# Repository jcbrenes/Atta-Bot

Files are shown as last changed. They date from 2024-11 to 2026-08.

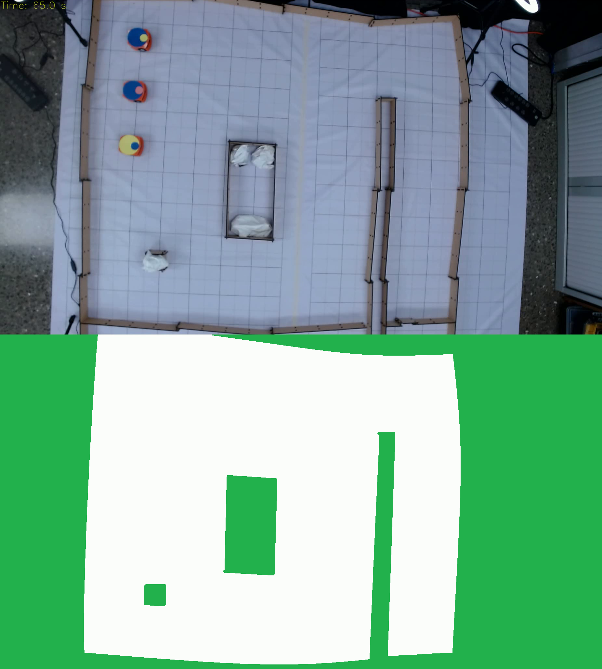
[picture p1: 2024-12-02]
Base/mask.png

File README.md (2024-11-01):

# Atta-Bot

Atta-Bot is a robotics system for swarm robotics research. Each Atta-Bot is a small, afordable and DIY mobile robot, but it also includes a base and camera system for robot tracking and position estimation.

Developed by the Multiple Robotics Research Group (GIRoM) at the Costa Rica Institute of Technology.

## Current Research Team
- Cindy Calderón Arce. ORCID: https://orcid.org/0000-0002-0077-225X  
- Rebeca Solís Ortega. ORCID: https://orcid.org/0000-0002-3065-8386  
- Juan Carlos Brenes Torres. ORCID: https://orcid.org/0000-0001-6323-2173  

## Folder directory
- Base -> Code for the computer running as the base with camera
- Docs -> Documentation on materials, construction, system architecture 
- Chassis -> Construction files and 3D models for the robot chassis
- Controller -> Code for the robot's microcontroller
- Scenario -> Construction files and 3D models for the swarm scenario 

## Coding standard
Please follow the coding or programming standard for any contribution to the project [Contributing.md]

[Contributing.md]: <https://github.com/jcbrenes/Atta-Bot/blob/main/Contributing.MD>

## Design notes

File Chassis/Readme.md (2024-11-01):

# Robot chassis 

Solid Works 3D files of robot chassis and 2D files for laser cutting.

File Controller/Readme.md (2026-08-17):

# Firmware del robot

Código C++ del microcontrolador de cada AttaBot. Un robot con este firmware
levanta WiFi, se anuncia a la estación base, obedece los comandos que le llegan
por UDP y ejecuta por su cuenta la navegación, la evasión de obstáculos y las
conductas de enjambre.

| carpeta | qué es |
|---|---|
| `AttaBot/` | el firmware normal, el que va en todos los robots |
| `HW_Test/` | diagnóstico de hardware sin WiFi — ver `Docs/HW_Test.md` |
| `IR_Calibration/` | calibración de los sensores infrarrojos |

---

## Qué hace falta

**Hardware:** ESP32 (módulo clásico, no S2/S3), dos motores DC con encoder y
puente H, dos sensores infrarrojos laterales, un APDS9960 al frente (proximidad y
color), una IMU ICM-20948, un anillo de LEDs y un marcador ArUco en la tapa.
El diagrama electrónico y la lista de materiales están en `Docs/`.

**Software:** el Arduino IDE (por su `arduino-cli` incorporado y su gestor de
librerías) o el `arduino-cli` suelto. Python 3 para `OTA.py`.

**Librerías**, con las versiones contra las que compila hoy:

| componente | versión |
|---|---|
| ESP32 Arduino core | 3.3.11 |
| FastLED | 3.10.5 |
| Adafruit APDS9960 | 1.3.1 |
| SparkFun ICM-20948 | 1.3.2 |

Estas versiones importan más de lo habitual: varias de estas librerías tienen
requisitos que **no se ven al compilar**. El sketch construye igual y el robot
arranca igual, y la falla aparece recién al moverlo. Las tres trampas conocidas
están en [Restricciones](#restricciones-que-hay-que-respetar), al final.

**Red:** los robots se conectan a un AP con el SSID y la contraseña que declara
`AttaBot/AttaBot.ino` (constantes `ssid` y `password`), y escuchan UDP en el
puerto 6060. Cada robot necesita IP fija en el router, y esa IP se anota en
`Base/configSystem.json` para que la base sepa a quién le habla.

---

## Compilar y subir

### La primera vez en cada robot: por USB

Obligatorio, porque `partitions.csv` cambia la tabla de particiones y eso no se
puede hacer por OTA — el OTA escribe en el slot de aplicación, nunca en la tabla.

```sh
cd Controller/AttaBot
arduino-cli compile --fqbn esp32:esp32:esp32:PartitionScheme=min_spiffs \
    --build-path build --upload --port /dev/ttyUSB0 .
arduino-cli monitor --port /dev/ttyUSB0 --config baudrate=115200
```

`arduino-cli board list` dice en qué puerto quedó el robot. Si se usa el que
viene dentro del Arduino IDE, el binario está en
`<instalación del IDE>/resources/app/lib/backend/resources/arduino-cli`.

> **`PartitionScheme=min_spiffs` no es decorativo.** `partitions.csv` le da al
> sketch un slot de 1.97 MB en vez de los 1.31 MB del layout por defecto. Sin
> declararlo, `arduino-cli` compila igual pero mide contra el slot equivocado y
> reporta 93 % de uso cuando el real es 62 %.

### Después: por aire

`OTA.py` compila y sube por WiFi en un solo paso, usando el `arduino-cli` del
IDE:

```sh
cd Controller/AttaBot
python3 OTA.py --build          # compila y sube a todos los robots
python3 OTA.py --build 101 104  # solo a .101 y .104
python3 OTA.py 101              # sube lo ya compilado
```

Antes de subir verifica que el `.bin` sea más nuevo que **todos** los `.ino` y
`.h` del sketch. Un OTA que sube un binario viejo es indistinguible de uno que
funciona, hasta que se prueba el robot.

### Desde VS Code

Las mismas operaciones están como tareas: `firmware: compilar y subir por USB`,
`ver puertos USB` y `monitor serie`. `vscode_setup.py` genera el
`c_cpp_properties.json` con las rutas del core de esta máquina (no se versiona,
porque son rutas absolutas).

---

## Estructura del sketch

Arduino concatena todos los `.ino` de la carpeta en una sola unidad de
traducción — primero el que se llama como la carpeta, después el resto en orden
alfabético. Por eso las constantes, las variables globales y las declaraciones
forward viven en `AttaBot.ino` y los demás archivos las ven directo, sin `extern`
ni cabeceras. La contra es que no hay encapsulación real: cualquier archivo puede
tocar cualquier global.

| archivo | qué lleva |
|---|---|
| `AttaBot.ino` | debug, pines, constantes, globales, declaraciones, ISR, `setup()` |
| `comandos.ino` | protocolo con la base y un handler por comando UDP |
| `estados.ino` | `loop()` y una función por estado de la FSM |
| `navegacion.ino` | navegación reactiva, congregación, MEET, dispersión, formaciones |
| `sensores.ino` | IR laterales, APDS9960 central, WiFi |
| `motores.ino` | PID por rueda, puente H, movimiento por distancia |
| `perifericos.ino` | LED, IMU y el EKF |
| `utils.h` | estructuras de estado y helpers inline |

El robot es una máquina de estados que consume una lista de instrucciones: los
comandos que llegan por UDP encolan instrucciones, y `loop()` ejecuta la que
toca. La lista de comandos y su sintaxis están en `Docs/comandos.md`; la
geometría de las formaciones, en `Docs/formaciones.md`.

Cada robot guarda en NVS su calibración propia (escala del giróscopo, pulsos por
revolución de los encoders, balance de blancos del sensor de color), así que dos
robots con el mismo binario no se comportan igual hasta calibrarlos. La rutina
guiada es `BASE.CALIBRATE|<id>` desde la consola de la base.

---

## Restricciones que hay que respetar

Tres detalles de las librerías rompen el robot **en silencio**: compilan bien y
la falla aparece recién al moverlo. Si algo de esto se toca, hay que verificarlo
en el arranque por serie.

### El PWM de los motores necesita el reloj APB

Los cuatro timers low-speed del LEDC **comparten un solo mux de reloj**. Los
motores van a 1 kHz / 14 bit, o sea 16.384 MHz de fuente, y eso sólo sale de APB
(80 MHz). Si otro periférico se queda con un reloj lento, los `ledcAttach()` de
los motores fallan y **las ruedas no reciben PWM: el robot no gira ni avanza**.

`setup()` deja el reloj explícito con `ledcSetClockSource(LEDC_USE_APB_CLK)`
antes de crear cualquier canal, así el reparto no se hereda de quien se attachee
primero. Si se monta un servo u otro periférico PWM:

- Dale **16 bits** de ancho de timer (pide 3.28 MHz → divisor 24 sobre APB), no
  los 10 por defecto. A 10 bits un servo pide 50 Hz × 2¹⁰ = 51.2 kHz, que desde
  APB daría divisor 1562 y no entra en el registro, así que el driver se va al
  reloj lento y arrastra a los motores.
- **No uses ESP32Servo 3.2.1**: su `attach()` pisa el ancho con el valor por
  defecto aunque la librería documente lo contrario. Sale más barato
  `ledcAttach(pin, 50, 16)` + `ledcWrite(pin, us << 16 / 20000)`.

Para verificarlo sin destapar nada, mirá el arranque por serie:

```
[3] Motores PWM: 1000Hz 14-bit (max=16383) OK — real=1000Hz
```

`FALLO`, o un `real=` distinto de 1000 Hz, es exactamente este problema.

### FastLED secuestra `radians()` — no la uses en este sketch

`FastLED.h` hace `#undef radians` y después `using fl::radians`. En el sketch
`radians()` **no es la macro de Arduino**, es esta plantilla:

```cpp
template<typename T>
constexpr inline T radians(T deg) { return deg * static_cast<T>(0.017453292519943295); }
```

La constante se castea al **tipo del argumento**. Con un ángulo entero,
`static_cast<int>(0.01745…)` es **0**, así que `radians(180)` devuelve **0** y
cualquier giro calculado desde un entero se vuelve un no-op silencioso. Con
`float` funciona bien.

El síntoma es característico porque separa los caminos por tipo: el robot
*navega* hacia el objetivo (la nav usa floats) pero *no esquiva* obstáculos
(ángulo de evasión entero), el random walk no gira y `TURN|grados` no hace nada
en ningún robot. Es fácil confundirlo con un problema de calibración por robot, y
no lo es.

Usá **`DegToRad()`** y **`DegToArc()`**, definidas al principio de `AttaBot.ino`:
toman `float` a propósito, para forzar la promoción en el call site, y usan la
constante literal sin depender de FastLED ni de `DEG_TO_RAD`.

La misma cabecera también reemplaza `abs`, `min`, `max`, `degrees` y `map`. Hoy
el firmware no usa `degrees()`, y `map()` sigue siendo la de Arduino (es función,
no macro), pero si aparece un cálculo raro con enteros, este es el primer lugar
donde mirar.

### El DMP de la IMU se activa editando la librería

`ICM_20948_USE_DMP` tiene que estar descomentado en `src/util/ICM_20948_C.h`
(línea ~34) de la librería de SparkFun. **Un update de la librería pisa esa
edición.** Sin DMP no hay yaw: `imuAvailable` queda en `false` y los giros caen
al lazo abierto por encoders, así que salen cortos o largos y la navegación
acumula error.

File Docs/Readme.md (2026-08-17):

# Documentation folder

Documentation for the Atta-Bot swarm robotics system

- Bill of Materials (BOM)
- User manual
- Robot assembly manual
- Chassis construction plans
- Electronic diagrams
- System Architecture and logic diagrams

| | |
|---|---|
| `comandos.md` | reference sheet for every command the base and the robots accept |
| `formaciones.md` | how the line / wedge / circle formations are computed and used |
| `HW_Test.md` | hardware diagnostic sketch |

Papers and study reports written on top of this platform are not kept here: they
have their own authors, deadlines and repositories. This folder documents the
platform itself, so that the work can be reproduced.

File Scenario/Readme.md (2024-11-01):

# Swarm scenario

Solid Works 3D models for the swarm scenario. Also 2D files for laser cutting the necessary parts.

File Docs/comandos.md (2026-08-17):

# Comandos de la Base — referencia

Todo lo que se le puede escribir a la consola de `AttaBot_Base.py` o a la caja de
comandos de la GUI. Las dos caras usan **el mismo despachador**, así que lo de
acá vale igual en ambas.

> La lista viva está en `_ROBOT_CMDS` y `_BASE_CMDS`, al principio de
> `Base/AttaBot_Base.py`. Son la fuente única del despachador, del autocompletado
> y de `HELP`. Si agregás un comando ahí, actualizá también esta hoja.

---

## La gramática

```
DESTINO.VERBO|arg|arg
```

| destino | qué hace | ejemplo |
|---|---|---|
| `BASE` | lo ejecuta la Base (orquesta, consulta, calibra) | `BASE.CALIBRATE\|1` |
| `<id>` | se envía tal cual por UDP a ese robot | `1.MOVE\|500` |
| `BROADCAST` | se envía tal cual a todos los robots | `BROADCAST.DISPERSE\|600` |

Los argumentos van **siempre con `|`**, nunca con espacios.

**Por qué `BASE.` y no el id del líder:** `CONGREGATION` y `FORMATION` existen
*también* como comandos del firmware. `1.CONGREGATION` sería ambiguo — ¿lo
orquesta la Base o se lo mando crudo al robot? Con `BASE.` no hay colisión
posible.

### En la consola

- **TAB** autocompleta: sin punto ofrece destinos, después del punto ofrece los
  verbos que corresponden a ese destino, y después de un `|` muestra la forma de
  los argumentos.
- **`HELP`** sola (sin prefijo) lista todo. **`BASE.HELP|MOVE`** explica uno.
- Flechas ↑↓ para el historial, que **persiste entre corridas** en
  `~/.attabot_history`.
- **`BREAK`** termina la corrida y cierra los logs y el video correctamente.

### Formas viejas

`CALIBRATE.1`, `FORMATION.linea 1 300`, `STATUS.x` y `CONGREGATION.1`
**siguen funcionando**, avisando una vez por verbo. Van a desaparecer; usá la
forma nueva.

`GOTO.1 1200 850` **ya no**: ese atajo era exactamente `1.GT|1200|850` con un
mensaje de más, así que se retiró junto con los alias del firmware.

---

## Comandos de la Base

| comando | qué hace |
|---|---|
| `BASE.HELP` | lista todo |
| `BASE.HELP\|<verbo>` | detalle de uno |
| `BASE.STATUS` | markers detectados y pose de cada robot |
| `BASE.CALIBRATE\|<id>` | calibración guiada de yaw y PPR |
| `BASE.CONGREGATION\|<líder>[\|<esp_mm>]` | congregación con líder (esp. 300) |
| `BASE.FORMATION\|<figura>\|<líder>[\|<esp_mm>]` | formación geométrica |
| `BASE.OCCLUDE\|<segundos>` | tapa la cámara virtual — **solo `--sim`** |

Figuras de `FORMATION`: **`linea`** (fila perpendicular al rumbo del líder),
**`cuna`** (V detrás del líder), **`circulo`** (anillo alrededor del líder).

---

## Comandos a los robots

Todos aceptan `<id>.` o `BROADCAST.`

### Movimiento directo

| comando | argumentos |
|---|---|
| `MOVE` | `<mm>` — positivo adelante, negativo atrás |
| `TURN` | `<grados>` |
| `WAIT` | `<ms>` |
| `RESET` | — reinicia el robot |

### Navegación a un punto

| comando | argumentos |
|---|---|
| `GT` | `<x>\|<y>[\|<segmento_mm>]` — navegación reactiva al punto |
| `ABORT_NAV` | — cancela la navegación en curso |
| `RANDOMW` | `[<segmento_mm>]` — caminata aleatoria |

> Hasta el 05-08 había además `GOTO`, `POSITIONGT` y `BUG2`. **No eran
> variantes**: los cuatro nombres caían en el mismo handler del firmware y el
> nombre ni llegaba adentro, así que daba exactamente igual cuál usaras. Se
> quedó `GT`.

### Enjambre

| comando | argumentos |
|---|---|
| `MEET` | `<x>\|<y>[\|<radio>]` — congregación sobre un punto, **sin líder**. Radio 150-600mm; vacío = lo calcula el firmware según cuántos robots hay |
| `DISPERSE` | `[<separación_mm>]` — separación objetivo, por defecto 600 |
| `CANCEL_CONGREGATION` | — corta congregación, formación o dispersión |
| `CONGREGATION` | `<slot>\|<x>\|<y>` — **crudo**; normalmente lo manda `BASE.CONGREGATION` |
| `FORMATION` | `<figura>\|<líder>\|<idx>\|<n>\|<eje>` — **crudo**, ídem |

### Calibración y control

| comando | argumentos |
|---|---|
| `GETPPR` | — consulta el PPR guardado |
| `SETPPR` | `<valor>\|TEMP` o `<valor>\|SAVE` |
| `PID` | `<kp>\|<ki>\|<kd>[\|SAVE]` |
| `KFPID` | `<q>\|<r>` — filtro de Kalman del PID |
| `SELFTEST` | `[<pwm%>]` — pulso a lazo abierto, por defecto 40% |
| `NAV_CONFIG` | `<clave>\|<valor>[\|SAVE]` |

Claves de `NAV_CONFIG`:
`YAW_SCALE` · `ARENA` (`|<w>|<h>`) · `SEGMENT_DIST` · `ARRIVAL_THRESHOLD` ·
`PARKING_DIST` · `WHEEL_DIST` · `GOAL_DEADBAND` · `REALIGN`

### Sensores

| comando | argumentos |
|---|---|
| `SENSOR_MASK` | `<L\|C\|R>\|<0\|1>` — **1 = ignorar** ese sensor |
| `SENSOR_THRESHOLD` | `<valor>` — umbral del IR central |
| `CLEAR_EVASION` | — limpia el estado de evasión |
| `RESET_EVASION` | — reinicia el contador de evasiones |
| `COLOR_READ` | `[<ganancia>\|<ms>]` — lectura RGBC del APDS9960; con argumentos fija la exposición (ganancia 1/4/16/64, integración 3-200 ms) |
| `COLOR_WB` | `[<R>\|<G>\|<B>]` o `RESET` — balance de blancos del sensor de color, propio de cada robot. Sin argumentos mide el patrón que tiene enfrente y lo guarda en NVS |
| `SEARCH_OBJECT` | — busca un objeto por color |

### Diagnóstico

| comando | argumentos |
|---|---|
| `GET_STATUS` | — estado completo: FSM, sensores, pose, yaw, IMU, EKF, calibración |
| `GET_YAW` | — solo el yaw de la IMU |
| `EKF_NAV` | `<0\|1>` — ⚠ **dejar en 0** (ver más abajo) |
| `CONFIG` | `SAVE\|<id>` — registra el robot en la Base |
| `SEND_COUNT_MESSAGE` | — contador de mensajes, para medir pérdida |

---

## Recetas

### Calibrar un robot

```
4.NAV_CONFIG|YAW_SCALE|1.0          resetear la escala
4.TURN|360                          ×3, anotar el error de cada uno
4.NAV_CONFIG|YAW_SCALE|<medido>|SAVE
4.SETPPR|574|TEMP                   valor de arranque
4.MOVE|500                          ×3, medir el recorrido real
4.SETPPR|<medido>|SAVE
```

O guiado: `BASE.CALIBRATE|4`

> El **PPR depende de la superficie** — absorbe el deslizamiento, no solo el
> encoder. Recalibrar al cambiar de piso, y no comparar valores entre sesiones
> sobre suelos distintos. Medido: el mismo robot dio 585.8 y 542.1 en pisos
> distintos, y ~2.8% de dispersión entre dos medidas seguidas. Si el PPR va a
> entrar en las métricas, usá tramos de 800-1000mm en vez de 500.

### Congregación (el escenario del paper)

```
BROADCAST.RANDOMW                   dispersar
BROADCAST.MEET|1200|850             congregar sobre un punto
```

Análisis: `python3 herramientas/analyze_logs.py --congregation`

### Dispersión

```
BROADCAST.DISPERSE|600
BROADCAST.CANCEL_CONGREGATION       para cortar
```

Los saltos se recortan a la arena **menos 350mm de inset**, o sea un área útil
de 1700×1050mm en la arena de 2400×1750. Con 4 robots, 600-700mm es cómodo;
**900mm o más no converge** y los robots quedan oscilando.

### Formación

```
BASE.FORMATION|linea|1
BASE.FORMATION|cuna|1|400
BASE.FORMATION|circulo|1|350
```

**Poné el líder cerca del centro.** Para `linea` y `cuna`, la Base valida que
*todos* los slots caigan dentro de la arena; si uno se sale te dice **cuál y por
cuántos mm**, y cuánto mover al líder. Con 3 seguidores y 300mm de espaciado la
fila necesita ±600mm libres a los costados; si la perpendicular no entra, cae
sola a la columna sobre el rumbo del líder y avisa.

**El `circulo` no se rechaza nunca.** Ahí el firmware usa `SafeRingSlotAngle`,
que agranda el radio hasta 2.5× y reparte los slots en el arco libre más largo
con su propio margen de pared. La Base solo avisa si el anillo nominal no entra
—porque el radio real puede terminar bastante mayor que el pedido— pero deja que
el robot resuelva.

Si a un seguidor no se le ve el marker, se le asigna **el slot que sobra** (no el
más cercano) y la Base lo avisa: puede cruzarse con los demás en el camino.

---

## Advertencias

**`EKF_NAV` va en 0.** El EKF corre pasivo y se mide contra el ArUco. Su error
mediano es bueno (24-89mm) pero diverge en episodios discretos de 6-20s, con p95
de hasta 2.7m. No confiarle la navegación hasta explicar esos episodios.
Criterio: p95 bajo 50mm para navegar, hasta ~150mm sirve solo para puentear
oclusiones cortas.

**Un comando mal escrito se descarta en silencio** *en el robot*. El firmware no
contesta si no reconoce el verbo. Ya pasó con un `CMD|MVE1.MOVE1.MOVE` que no
hizo nada y parecía un robot colgado.

Desde el 05-08 **la Base avisa antes de enviarlo**:

```
⚠ 'GOTO' no es un comando del firmware — se envía igual, pero el robot
  lo va a descartar sin avisar. BASE.HELP los lista.
```

Solo avisa, no bloquea. Aun así, si un robot "no obedece", buscá su fila `CMD|`
en el ConsoleLog antes de sospechar del hardware.

**`SENSOR_MASK` usa 1 para IGNORAR**, no para activar. Es al revés de lo que
parece.

---

## Dónde queda todo

| qué | dónde |
|---|---|
| Comandos enviados | `ConsoleLogs/Console_Log_*.csv`, filas `CMD|` |
| Poses y EKF | `PositionLogs/Position_Log_*.csv` |
| Ritmo del lazo | `Logs/Time_Log_*.csv` |
| Video | `Videos/Video_*.avi` |

La telemetría de alta frecuencia (`POSE`, `POSITION_RESPONSE`,
`LEADER_POSITION`, `NEIGHBOR_POSITIONS`) **no** se registra a propósito: taparía
el ConsoleLog.

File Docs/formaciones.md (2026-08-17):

# Formaciones

Cómo un grupo de robots diferenciales se acomoda en **línea**, **cuña** o
**círculo** alrededor de un líder que se mueve: qué decide la estación base, qué
difunde el líder y qué calcula cada seguidor por su cuenta.

Este documento describe la geometría tal como corre hoy en el firmware
(`Controller/AttaBot/navegacion.ino`) y en la base
(`Base/AttaBot_Base.py`), para poder reproducir el comportamiento o modificarlo
sin releer las dos implementaciones.

---

## Cómo se pide

Desde la consola de la base:

```
BASE.FORMATION|<figura>|<líder>[|<esp_mm>]
```

| | |
|---|---|
| `<figura>` | `linea` (fila perpendicular al rumbo del líder), `cuna` (V hacia atrás), `circulo` (anillo alrededor del líder) |
| `<líder>` | id del robot que define el marco de referencia; los demás lo siguen |
| `<esp_mm>` | espaciado, 300 mm por defecto |

Ejemplos:

```
BASE.FORMATION|linea|1|300      # fila de 300 mm de paso, líder Atta_1
BASE.FORMATION|cuna|1|400
BASE.FORMATION|circulo|2        # anillo de radio nominal 300 mm
```

La base no manda destinos: manda a cada seguidor su **índice de slot**, una sola
vez, con dos comandos del firmware:

```
NAV_CONFIG|PARKING_DIST|<esp_mm>
FORMATION|<figura>|<líderID>|<idx>|<n>|[eje°]
```

El líder recibe el mismo comando con índice 0 (lo ignora) para saber que tiene
que difundir su pose.

---

## El reparto de trabajo

Una formación se podría resolver entera en la base: ve a todos los robots por la
cámara cenital y podría calcular cada destino. No se hace así porque el líder
**se mueve**; si la base tuviera que recalcular y retransmitir cada destino con
cada centímetro que avanza, la formación viviría al ritmo del enlace inalámbrico
y se rompería con cada paquete perdido.

El trabajo se parte en tres, según qué información hace falta para cada decisión:

| decisión | quién | cuándo |
|---|---|---|
| qué slot le toca a cada robot | la base — es la única que los ve a todos, y sin vista global no se pueden evitar los cruces | una sola vez |
| dónde está el marco de referencia | el líder, por difusión — la formación se define respecto de **él**, no de la arena | continuo, 4 Hz |
| dónde queda mi slot y cómo llego | cada seguidor, local | con cada pose del líder |

```
   Base + cámara                Líder                    Seguidor i
   ve a todos                   define el marco          calcula dónde
   decide QUÉ slot              de referencia            S = L + k·s·â
        |                            |                        ^
        |  POSE 20 Hz ────────────►  |  LEADER_POSITION 4 Hz ─┘
        |                                                     ^
        |  FORMATION|figura|líder|idx|n|eje  (una sola vez) ───┘
        |  POSE 20 Hz ────────────────────────────────────────┘
```

Si la base se cae después de repartir los índices, la formación sigue viva: los
seguidores tienen todo lo que necesitan mientras el líder siga difundiendo.
Cortar la difusión del líder sí la rompe. Ese es el grado intermedio de
centralización de la plataforma, entre el comando central robot por robot y la
coordinación puramente local.

### Notación

| símbolo | qué es |
|---|---|
| `L`, `θL` | posición y rumbo del líder |
| `s` | espaciado pedido, en mm (`NAV_CONFIG\|PARKING_DIST`) |
| `n` | cantidad de seguidores |
| `i` | índice de slot del seguidor, `0 ≤ i < n` |
| `α` | giro opcional del eje de la fila |
| `ĥ`, `p̂` | versores del rumbo del líder y del eje de la fila |
| `â` | versor del brazo sobre el que se reparten los slots |
| `Sᵢ` | posición del slot `i` |
| `Wᵢ` | waypoint de aproximación (*staging*) del slot `i` |

---

## Etapa 1: la base reparte los slots

El problema no es dónde poner los robots, que lo fija la figura, sino **cuál va
en cuál**. Con tres seguidores hay seis asignaciones posibles y cinco de ellas
hacen que al menos dos robots se crucen de camino. Cruzarse en una arena chica
con navegación reactiva significa que se detectan mutuamente como obstáculo, se
evaden, y la formación tarda el doble o entra en bloqueo.

La solución es un **emparejamiento monótono**: se proyecta cada seguidor sobre el
eje de la fila, se ordenan los slots sobre ese mismo eje, y se emparejan por
rango — el que ya está más a la izquierda recibe el slot más a la izquierda.

```
p̂     = (cos(θL + 90° + α), sin(θL + 90° + α))     eje de la fila
κ(j)  = (Pj − L) · p̂                               clave del seguidor j
κs(i) = σ(i) · k(i)                                 clave del slot i
```

`k(i)` y `σ(i)` son el anillo y el lado que se definen en la etapa 3. Para el
círculo las claves son angulares: `κ(j) = atan2(yj − yL, xj − xL) mod 2π` y
`κs(i) = 2πi/n`. Ambas listas se ordenan de menor a mayor y se emparejan por
posición en el orden.

### Por qué el orden por rango no cruza

Sean `a₁ ≤ a₂ ≤ … ≤ aₙ` las coordenadas de los seguidores sobre el eje `p̂` y
`b₁ < b₂ < … < bₙ` las de los slots sobre ese mismo eje. Si cada seguidor `i` va
al slot `i` por un segmento recto, su coordenada proyectada en el instante
normalizado `t ∈ [0,1]` es la interpolación `pᵢ(t) = (1−t)·aᵢ + t·bᵢ`, y para un
par `i < j`:

```
pj(t) − pi(t) = (1−t)·(aj − ai) + t·(bj − bi)
```

Por construcción del emparejamiento por rango, `j > i` implica `aj ≥ ai` y
`bj > bi`, así que ambos sumandos son no negativos y el segundo es estrictamente
positivo para `t > 0`. Una combinación convexa de cantidades no negativas no
cambia de signo: la diferencia se mantiene positiva en todo el recorrido, y dos
puntos con distinta proyección sobre `p̂` son distintos. No hay cruce.

El recíproco explica por qué cualquier otra asignación falla: introduce al menos
una inversión (`ai < aj` pero `bi > bj`), ahí los dos sumandos tienen signos
opuestos, la diferencia es continua y cambia de signo, y por el teorema del valor
intermedio se anula en algún `t` interior. **Ese cero es el cruce.**

```
      por rango: 0 cruces              orden invertido: 2 cruces
      o───────────────□                o──────╲   ╱──────□
      o───────────────□                o───────╳─╳───────□
      o───────────────□                o──────╱   ╲──────□
   (o = seguidor, □ = slot sobre el eje de la fila)
```

### Qué no garantiza

La garantía es limpia pero angosta, y vale más saber dónde termina:

- **Es sobre la geometría planificada, no sobre la trayectoria ejecutada.** Los
  robots no van en línea recta: pasan por un waypoint de aproximación, avanzan a
  velocidades distintas y desvían por evasión reactiva. Dice que los *destinos*
  no obligan a cruzarse, no que el recorrido real no lo haga.
- **Es topológica, no métrica.** Conserva el orden, no la separación: dos robots
  pueden mantener el orden y aun así acercarse lo suficiente para dispararse la
  evasión por infrarrojo.
- **Supone el líder quieto durante el tránsito.** Si se mueve, los slots se
  mueven con él y las `bᵢ` dejan de ser constantes.
- **Los robots que la cámara no ve quedan fuera del argumento.** Reciben
  `κ = +∞` y el slot que sobra, de modo que su posición real no participa del
  orden, y la base lo advierte por consola. Devolver `0` en vez de `+∞` es peor
  que no ordenar: `0` es una coordenada lateral perfectamente válida, así que un
  robot invisible se cuela entre los visibles y les corre el slot a todos,
  degradando la asignación en silencio justo cuando más falta hace.
- **El círculo no hereda la garantía.** Sobre una circunferencia el orden es
  cíclico y el corte en 0° es arbitrario: el emparejamiento sin cruces en un
  ciclo exige elegir el desplazamiento rotacional correcto entre `n` posibles, y
  ordenar por rango con un corte fijo es sólo uno de esos `n`. Para el círculo la
  asignación es una heurística razonable, no un teorema.

### Validación contra la arena

Antes de transmitir nada, la base comprueba que todo slot caiga dentro de la
arena con un margen de 250 mm respecto de las paredes. Si una fila perpendicular
no cabe, se reintenta con el eje girado `α = 90°` — la fila se vuelve columna —
antes de rechazar. Si aun así no cabe, el mensaje de error indica qué slot falla
y por cuántos milímetros: un rechazo por 9 mm y uno por medio metro exigen
acciones distintas del operador.

El círculo es la excepción y no se valida acá, porque el firmware lo resuelve con
su propio algoritmo de anillo seguro y compararlo contra un anillo plano de radio
nominal sólo producía rechazos falsos.

> Las dimensiones de la arena se configuran con `NAV_CONFIG|ARENA`; no están
> tomadas del tamaño del cuadro de la cámara, que es otra cosa.

---

## Etapa 2: el líder difunde su pose

El líder recibe su propia pose de la base a unos 20 Hz y la reemite por difusión
(`LEADER_POSITION`), limitada a **4 Hz**. Reemitir las veinte saturaría el enlace
sin aportar nada, porque los seguidores no replanifican más rápido que eso. Al ir
por difusión, un seguidor más no cuesta un mensaje más.

Antes de difundir, la pose pasa por una media móvil de `N = 4` muestras. El
ángulo no se puede promediar directamente — entre 359° y 1° el promedio
aritmético da 180°, exactamente el lado contrario — así que se promedian el seno
y el coseno y se recompone:

```
x̄ = (1/N)·Σ xt          ȳ = (1/N)·Σ yt
θ̄ = atan2( Σ sin θt , Σ cos θt )
```

La ventana se vacía si la muestra nueva cae a más de 100 mm de la media vigente:
en ese caso el líder se movió de verdad, o la cámara lo leyó mal, y en cualquiera
de los dos casos promediar con lo viejo introduce un retardo que miente.

Del lado del seguidor hay una segunda defensa contra el ruido: el objetivo de
navegación sólo se reubica si el nuevo cae a más de **40 mm** del actual. Sin esa
banda muerta el destino se corre unos milímetros con cada mensaje y el navegador
termina re-apuntando contra el ruido de la localización visual en vez de contra
el movimiento real del líder.

---

## Etapa 3: el seguidor calcula su slot

Cada seguidor conoce cuatro cosas: la pose del líder que acaba de llegar, su
índice `i`, el total `n` y el espaciado `s`. Con eso arma la posición de su slot
sin hablar con nadie.

El índice se descompone en **anillo** y **lado**: los pares van a un lado, los
impares al otro, y cada par de índices sube un anillo.

```
k(i) = ⌊i/2⌋ + 1                 anillo (1, 1, 2, 2, 3, …)
σ(i) = +1 si i es par, −1 si impar
```

Con `ĥ = (cos θL, sin θL)` y `p̂` el eje de la fila, la dirección del brazo y la
posición del slot son:

```
        ⎧ σ(i)·p̂                    línea
â(i) =  ⎨
        ⎩ (σ(i)·p̂ − ĥ)/√2          cuña

Sᵢ   = L + k(i)·s·â(i)
```

```
      línea                    cuña                    círculo
        □ 2                        □ 2
        □ 0                   ╲                          □ 1
   ●───────►ĥ                   □ 0                    ●──────□ 0  ĥ
        □ 1                   ●───────►ĥ                  □ 2
                                □ 1  ╱                 (anillo seguro)
   â = σ·p̂                 â = (σ·p̂ − ĥ)/√2
```

La normalización de la cuña **no es cosmética**. Como `p̂` y `ĥ` son unitarios y
perpendiculares, `‖σ·p̂ − ĥ‖ = √2`; dividir por `√2` es lo que hace que `s`
signifique lo mismo en las dos figuras: distancia del líder al primer slot, y
separación entre slots consecutivos del mismo brazo. Sin ese `1/√2` el slot `k`
queda a `k·s·1,414` del líder — 566 mm cuando se piden 400. Que el brazo caiga
exactamente a 135° se sigue de la misma cuenta:

```
â·ĥ = (σ·(p̂·ĥ) − ĥ·ĥ)/√2 = (0 − 1)/√2 = −√2/2   ⟹   ∠(â, ĥ) = 135°
```

> **La fórmula del slot está escrita dos veces**: en el firmware, que la usa para
> navegar (`UpdateCongregationGoal` en `navegacion.ino`), y en la base, que la
> replica para validar contra los límites de la arena (`slotOffset` en
> `AttaBot_Base.py`). Cualquier cambio toca los dos archivos; tocar sólo el
> firmware deja a la base rechazando formaciones que en realidad caben.

### El anillo seguro del círculo

Un anillo de radio fijo alrededor de un líder pegado a la pared pone la mitad de
los slots fuera de la arena. En vez de rechazar la formación, el firmware busca
un anillo que sí entre (`SafeRingSlotAngle`): prueba radios crecientes
`g ∈ {1; 1,2; 1,4; 1,7; 2,0; 2,5}` sobre el radio nominal, muestrea cada uno en
72 puntos, y se queda con el arco contiguo más largo que respeta 200 mm de margen
a las paredes. Acepta ese radio si el arco alcanza para todos:

```
R · arco ≥ n · 250 mm            φᵢ = a₀ + (i + ½)·arco/n
```

Los 250 mm por robot son el espacio mínimo para que no se toquen. Si ningún radio
cumple, se usa el mayor y se aprieta: mejor una formación apretada que ninguna.

---

## Etapa 4: la entrada por aproximación

Conocer el slot no basta: la recta desde donde está el robot hasta su slot puede
pasar por encima del líder o cruzar el slot de un vecino. Por eso la navegación
es en dos tramos, y el punto intermedio depende de la figura:

```
       ⎧ Sᵢ − 150·ĥ                             línea y cuña
Wᵢ  =  ⎨
       ⎩ L + (R + 150)·(cos φᵢ, sin φᵢ)         círculo
```

En línea y cuña el waypoint queda 150 mm por detrás del slot, de modo que cada
robot entra por su propio carril, paralelo al de los demás. En círculo la
aproximación es radial: se entra desde afuera del anillo, nunca cruzándolo.

Al alcanzar `Wᵢ` el robot marca la etapa como cumplida y el objetivo pasa a ser
`Sᵢ`. De ahí en más sigue recalculando el slot con cada difusión del líder, así
que si el líder se mueve la formación lo acompaña.

El arranque de la flota se escalona con una espera de `200 ms × id` para que los
robots no salgan todos en el mismo instante.

---

## Secuencia completa

**Base, una sola vez:**

```
tomar pose del líder; si no es visible, abortar
F ← todos los robots menos el líder;  n ← |F|;  α ← 0
si figura ≠ círculo y algún slot se sale de la arena:
    si figura = línea y con α = 90° sí cabe:  α ← 90°      (la fila es columna)
    si no: informar qué slot falla y por cuántos mm; abortar
p̂ ← eje de la fila(θL, α)
para cada j en F:
    κ[j] ← +∞                        si j no es visible   (al final, NO al medio)
           atan2(yj−yL, xj−xL) mod 2π   si figura = círculo
           (Pj − L)·p̂                   en otro caso
F* ← F ordenado por κ;   S* ← [0…n−1] ordenado por κs
para r en 0…n−1:
    enviar a F*[r]:  NAV_CONFIG|PARKING_DIST|s
                     FORMATION|figura|líder|S*[r]|n|α
enviar al líder: FORMATION|figura|líder|0|n|α                (su índice se ignora)
```

**Firmware, en cada seguidor:**

```
al recibir FORMATION:
    guardar figura, i, n, α;  esLíder ← (líder = miID)
    slotFijado ← falso;  aproximaciónHecha ← falso
    encolar Esperar(200 ms × miID);  encolar PedirPosición

al recibir LEADER_POSITION (≈4 Hz):
    L, θL ← suavizar(x, y, θ)        media móvil circular, N = 4
    recalcularObjetivo()

recalcularObjetivo():
    ĥ ← (cos θL, sin θL);   p̂ ← eje de la fila(θL, α)
    si figura ∈ {línea, cuña}:
        k ← ⌊i/2⌋+1;   σ ← +1 si i par, −1 si impar
        â ← σ·p̂;   si figura = cuña: â ← (â − ĥ)/√2      (rayo a 135°, unitario)
        S ← L + k·s·â
        W ← S si aproximaciónHecha, si no S − 150·ĥ
    si no (círculo):
        si ¬slotFijado:
            rumbo ← atan2(yYo − yL, xYo − xL)            exige pose propia fresca
            φ, R ← ánguloDeAnilloSeguro(L, i, n, s, rumbo)
            slotFijado ← verdadero
        S ← L + R·(cos φ, sin φ)
        W ← L + (R + 150 si falta aproximación)·(cos φ, sin φ)
    si ‖W − objetivo‖ > 40 mm:  objetivo ← W             banda muerta vs. ruido

al llegar al objetivo:
    si ¬aproximaciónHecha: aproximaciónHecha ← verdadero; recalcularObjetivo()
    si no: quedarse, siguiendo al líder mientras siga difundiendo
```

**Anillo seguro (sólo círculo):**

```
para cada g en {1; 1,2; 1,4; 1,7; 2,0; 2,5}:
    R ← R₀·g
    marcar cuáles de 72 puntos del anillo caen a ≥ 200 mm de toda pared
    si los 72 son seguros: devolver reparto uniforme, radio R
    arco ← la racha circular contigua más larga de puntos seguros
    si R·arco ≥ n·250 mm  o  g es el último:
        devolver a₀ + (i + ½)·arco/n, radio R
```

---

## Precisión medida

Cuatro robots (un líder y tres seguidores) en una arena de 2,4 × 1,75 m, con
localización por ArUco cenital y odometría corregida por cámara. Distancia y
ángulo de cada seguidor respecto del líder al final de la corrida; el ángulo se
mide desde el rumbo del líder.

**Línea**, `s = 300 mm` — tres corridas:

| slot −300 | slot +300 | slot +600 |
|---|---|---|
| 319 mm / −87° | 311 mm / +86° | 605 mm / +91° |
| 316 mm / −86° | 294 mm / +89° | 769 mm / +108° |
| 313 mm / +91° | 297 mm / −92° | 593 mm / +91° |

La mejor corrida cierra con **7 mm** de error en el slot más lejano y menos de 2°
de desviación angular. El único fallo — el slot lejano de la segunda corrida —
fue de un robot cuyo marcador fiducial se perdía de vista con frecuencia, así que
navegaba sin realimentación visual: es un problema del marcador, no de la lógica
de slots.

**Cuña**, `s = 400 mm` — mediana de los últimos 8 s del registro de posiciones:

| | slot +135° | slot −135° | slot +135° (k = 2) |
|---|---|---|---|
| pedido | 400 mm | 400 mm | 800 mm |
| medido | 423 mm (+23) | 425 mm (+25) | 837 mm (+37) |

El residuo de 23–37 mm queda por debajo de la tolerancia de llegada de 50 mm, y
es del mismo orden que el de la línea. Los ángulos se mantuvieron entre ±131° y
±139°.

Un error de escala en la geometría del slot tiene una firma reconocible: **un
factor constante repartido por igual entre todos los slots**, con los ángulos
correctos. Si los tres seguidores quedan a `×1,41` de lo pedido, el sospechoso es
la normalización de la cuña, no la calibración de los robots.

---

## Límites conocidos

1. **El círculo no está validado en hardware.** Es la única de las tres figuras
   que no se ha ejecutado con robots reales, y además la única cuyo espaciado lo
   puede reescribir el anillo seguro.
2. **El espaciado del círculo no significa lo mismo que el de las otras dos
   figuras.** En línea y cuña `s` es exactamente la distancia al primer slot; en
   círculo es un radio *nominal* que el anillo seguro puede multiplicar hasta 2,5
   veces. Quien pida 400 mm en las tres figuras obtiene tres geometrías
   distintas, y hoy eso sólo se advierte por consola.
3. **La asignación anti-cruce es monótona, no óptima.** Minimiza cruces, que es
   lo que rompe la formación, pero no la distancia total recorrida. Con cuatro
   robots la diferencia no se nota; con diez podría.
4. **Ningún seguidor sabe de los demás.** Si dos se estorban en el camino, lo
   resuelve la evasión reactiva, no la formación. Es coherente con el diseño
   descentralizado, pero significa que el tiempo de convergencia depende de la
   configuración inicial.

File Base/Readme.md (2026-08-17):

## Base Directory

Python code for computer running as swarm base.

System requierements:
- 1080p webcam placed on ceiling
- Python version ...

## Qué hay acá

En la raíz vive lo que corre durante un experimento, y nada más. Todo lo demás
está agrupado por para qué sirve.

| | |
|---|---|
| `AttaBot_Base.py` | el programa: cámara, ArUco, protocolo UDP y logging |
| `AttaBot_GUI.py` | su interfaz |
| `configSystem.json` | configuración del sistema de visión y de la red |
| `cameraMatrix.txt`, `dist.txt`, `mask.png` | calibración de la cámara |

`configSystem.json` nombra `cameraMatrix.txt` y `dist.txt` con rutas **relativas
al directorio de trabajo**, y la Base corre desde acá. Por eso esos tres archivos
se quedan en la raíz y no en una subcarpeta: moverlos rompe el arranque en el lab
salvo que se editen a la vez el JSON y `herramientas/Calibrar.py`, que es quien
los escribe.

### `herramientas/` — análisis, banco, calibración y diagnóstico

| | |
|---|---|
| `analyze_logs.py` | métricas de navegación por corrida y por campaña |
| `scan_logs.py` | escáner de anomalías sobre todos los logs |
| `recortar_video.py` | recorta los videos por el reloj de los logs |
| `check_system.py` | verifica cámara, red y dependencias |
| `ir_check.py` | infrarrojos y sensor de color: monitor, umbral, calibración |
| `turn_check.py` | mide el error de giro contra los logs de posición |
| `aruco_test.py` | detección de markers en vivo |
| `Calibrar.py` | calibración de cámara; escribe `cameraMatrix.txt` |
| `calibrar_colores.py` | umbrales de color |
| `marker_acrilico.py` | genera los SVG de corte de los markers |
| `test_network_config.py` | prueba de la configuración de red |
| `ValidacionRandomWalk.py` | validación del random walk |

Se corren desde `Base/`, no desde adentro de `herramientas/`, porque la ruta a la
calibración de la cámara es relativa al directorio de trabajo:

```sh
python herramientas/analyze_logs.py            # sesión más reciente
python herramientas/analyze_logs.py --all      # histórico
python herramientas/scan_logs.py
```

### Directorios de datos

`PositionLogs/` y `ConsoleLogs/` guardan los logs de cada corrida; `Videos/` y
`Logs/`, el video cenital y el mapa cuadro↔tiempo. **Ninguno se versiona**: los
datos de cada campaña se archivan aparte, junto al trabajo que los usa.

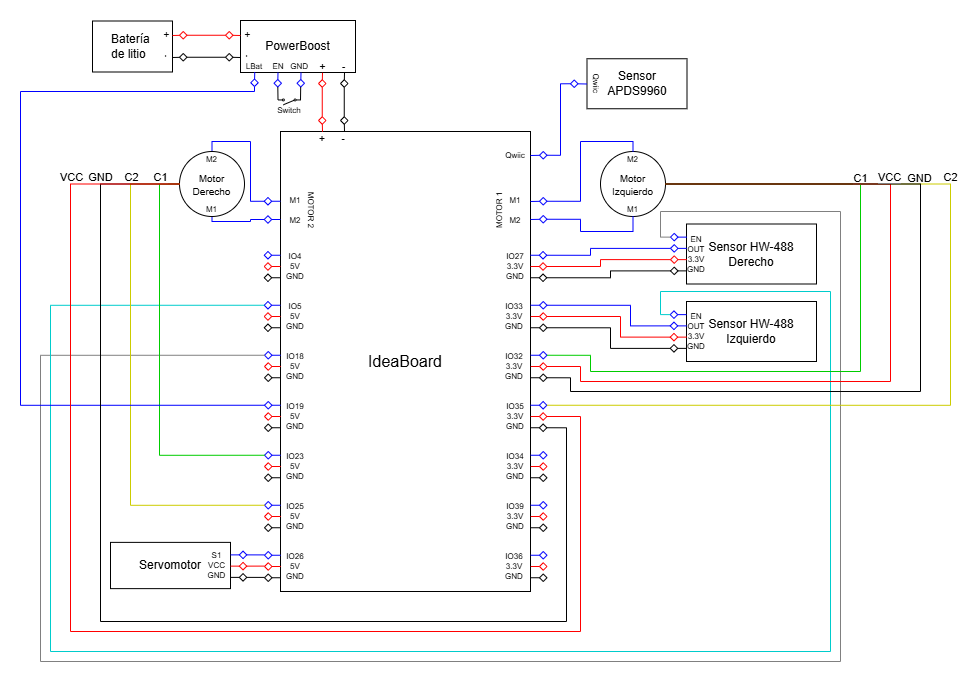
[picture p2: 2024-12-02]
Docs/ElectronicDiagram.png

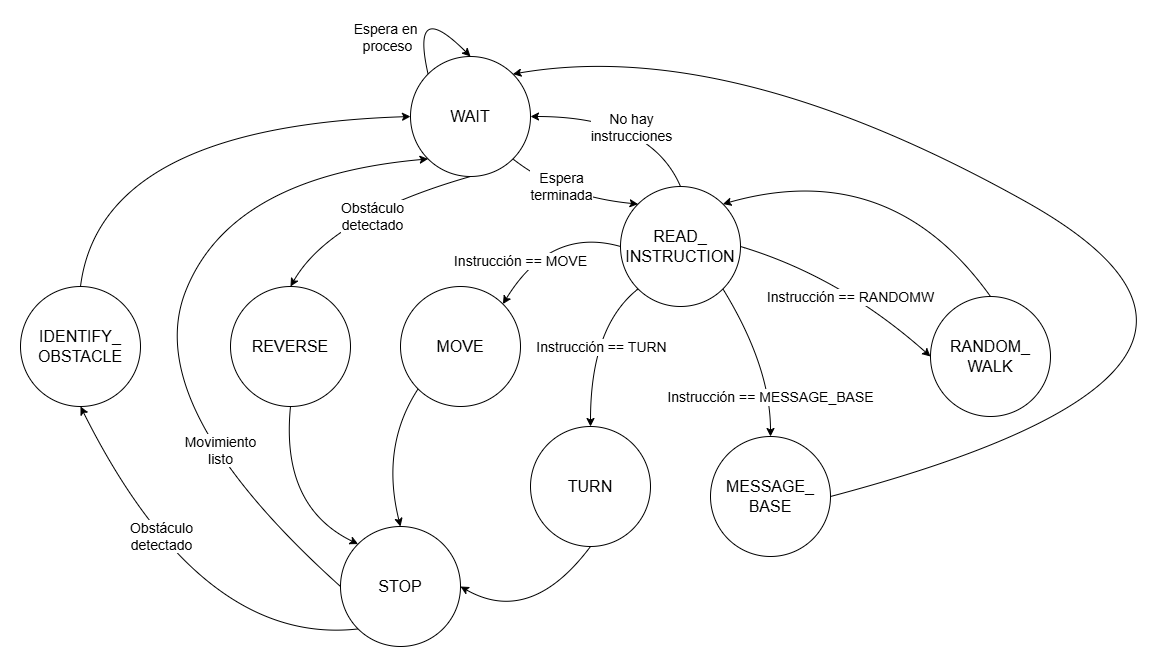
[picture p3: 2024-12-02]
Docs/FSM.png

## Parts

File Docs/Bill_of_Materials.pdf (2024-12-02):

Canti (http://www.crcibernetica.com/n20-gearmotor-with-encoder-and-wheel/)da (https://www.crcibernetica.com/lithium-ion-polymer-battery-3-7v-2500mah/)d (http://www.crcibernetica.com/powerboost-1000-charger-rechargeable-5v-lipo-usb-boost-1a-1000c/) | No (https://www.crcibernetica.com/mg90s-micro-servo-with-metal-gears/)mb (https://www.crcibernetica.com/infrared-obstacle-avoidance-module/)re (http://www.crcibernetica.com/apds9960-proximity-light-rgb-and-gesture-sensor-stemma-qt-qwiic/) | SKU | Link | Costo CR /u
2 (https://www.crcibernetica.com/lithium-ion-polymer-battery-3-7v-2500mah/) | Mot (https://www.crcibernetica.com/3pi-n20-ball-caster/)or (https://www.crcibernetica.com/crcibernetica-ideaboard/) cd (https://www.crcibernetica.com/mg90s-micro-servo-with-metal-gears/) con (https://www.crcibernetica.com/infrared-obstacle-avoidance-module/) enc (http://www.crcibernetica.com/apds9960-proximity-light-rgb-and-gesture-sensor-stemma-qt-qwiic/)od (https://www.crcibernetica.com/dupont-connector-assorted-kit/)er (https://www.crcibernetica.com/m3-nylon-screw-black-hex-screw-nut-nylon-pcb-standoff-assortment-kit-250pcs/) | ROB-CB0N20 | https://www.crcibernetica.com/n20-gearmotor-with-encoder-and-wheel/ | $14.95
1 | B (https://www.crcibernetica.com/crcibernetica-ideaboard/)ate (https://www.crcibernetica.com/mg90s-micro-servo-with-metal-gears/)ría (https://www.crcibernetica.com/infrared-obstacle-avoidance-module/) Lip (http://www.crcibernetica.com/apds9960-proximity-light-rgb-and-gesture-sensor-stemma-qt-qwiic/)o (https://www.crcibernetica.com/dupont-connector-assorted-kit/) | ADA-328 | https://www.crcibernetica.com/lithium-ion-polymer-battery-3-7v-2500mah/ | $17.95
1 (https://www.crcibernetica.com/lithium-ion-polymer-battery-3-7v-2500mah/) | B (https://www.crcibernetica.com/micro-gearmotor-support-bracket/)oo (https://www.crcibernetica.com/3pi-n20-ball-caster/)st (https://www.crcibernetica.com/crcibernetica-ideaboard/) Bate (https://www.crcibernetica.com/mg90s-micro-servo-with-metal-gears/)ry (https://www.crcibernetica.com/infrared-obstacle-avoidance-module/) má (http://www.crcibernetica.com/apds9960-proximity-light-rgb-and-gesture-sensor-stemma-qt-qwiic/)nag (https://www.crcibernetica.com/dupont-connector-assorted-kit/)er (https://www.crcibernetica.com/m3-nylon-screw-black-hex-screw-nut-nylon-pcb-standoff-assortment-kit-250pcs/) | ADA-2465 | https://www.crcibernetica.com/powerboost-1000-charger-rechargeable-5v-lipo-usb-boost-1a-1000c/ | $32.95
2 (https://www.crcibernetica.com/lithium-ion-polymer-battery-3-7v-2500mah/) | So (https://www.crcibernetica.com/crcibernetica-ideaboard/)por (https://www.crcibernetica.com/mg90s-micro-servo-with-metal-gears/)te (https://www.crcibernetica.com/infrared-obstacle-avoidance-module/) Mot (http://www.crcibernetica.com/apds9960-proximity-light-rgb-and-gesture-sensor-stemma-qt-qwiic/)or (https://www.crcibernetica.com/dupont-connector-assorted-kit/) | ROB-CB02443 | https://www.crcibernetica.com/micro-gearmotor-support-bracket/ | $0.75
1 (https://www.crcibernetica.com/lithium-ion-polymer-battery-3-7v-2500mah/) | Ball (https://www.crcibernetica.com/mg90s-micro-servo-with-metal-gears/) Ca (https://www.crcibernetica.com/infrared-obstacle-avoidance-module/)ste (http://www.crcibernetica.com/apds9960-proximity-light-rgb-and-gesture-sensor-stemma-qt-qwiic/)r (https://www.crcibernetica.com/dupont-connector-assorted-kit/) | ROB-CB1818 | https://www.crcibernetica.com/3pi-n20-ball-caster/ | $2.75
1 (https://www.crcibernetica.com/lithium-ion-polymer-battery-3-7v-2500mah/) | Ide (https://www.crcibernetica.com/mg90s-micro-servo-with-metal-gears/)aBo (https://www.crcibernetica.com/infrared-obstacle-avoidance-module/)ard (http://www.crcibernetica.com/apds9960-proximity-light-rgb-and-gesture-sensor-stemma-qt-qwiic/) | ROB-CBIB01 | https://www.crcibernetica.com/crcibernetica-ideaboard/ | $39.95
1 (https://www.crcibernetica.com/lithium-ion-polymer-battery-3-7v-2500mah/) | S (https://www.crcibernetica.com/crcibernetica-ideaboard/)ervom (https://www.crcibernetica.com/infrared-obstacle-avoidance-module/)oto (http://www.crcibernetica.com/apds9960-proximity-light-rgb-and-gesture-sensor-stemma-qt-qwiic/)r (https://www.crcibernetica.com/dupont-connector-assorted-kit/) | MG90S | https://www.crcibernetica.com/mg90s-micro-servo-with-metal-gears/ | $6.95
3 (https://www.crcibernetica.com/lithium-ion-polymer-battery-3-7v-2500mah/) | Sen (https://www.crcibernetica.com/crcibernetica-ideaboard/)sor (https://www.crcibernetica.com/mg90s-micro-servo-with-metal-gears/) HW-4 (http://www.crcibernetica.com/apds9960-proximity-light-rgb-and-gesture-sensor-stemma-qt-qwiic/)88 (https://www.crcibernetica.com/dupont-connector-assorted-kit/) | SEN-CB0006 | https://www.crcibernetica.com/infrared-obstacle-avoidance-module/ | $2.95
1 (https://www.crcibernetica.com/lithium-ion-polymer-battery-3-7v-2500mah/) | Se (https://www.crcibernetica.com/3pi-n20-ball-caster/)nso (https://www.crcibernetica.com/crcibernetica-ideaboard/)r (https://www.crcibernetica.com/mg90s-micro-servo-with-metal-gears/) APD (https://www.crcibernetica.com/infrared-obstacle-avoidance-module/)S9960 (https://www.crcibernetica.com/dupont-connector-assorted-kit/) | ADA-3595 | https://www.crcibernetica.com/apds9960-proximity-light-rgb-and-gesture-sensor-stemma-qt-qwiic/ | $11.95
1 (https://www.crcibernetica.com/lithium-ion-polymer-battery-3-7v-2500mah/) | Kit co (https://www.crcibernetica.com/mg90s-micro-servo-with-metal-gears/)nec (https://www.crcibernetica.com/infrared-obstacle-avoidance-module/)tor (http://www.crcibernetica.com/apds9960-proximity-light-rgb-and-gesture-sensor-stemma-qt-qwiic/)es | KIT-CB0012 | https://www.crcibernetica.com/dupont-connector-assorted-kit/ | $8.95
1 (https://www.crcibernetica.com/lithium-ion-polymer-battery-3-7v-2500mah/) | Kits espaciadores (http://www.crcibernetica.com/apds9960-proximity-light-rgb-and-gesture-sensor-stemma-qt-qwiic/) | TOL-CB0513 | https://www.crcibernetica.com/m3-nylon-screw-black-hex-screw-nut-nylon-pcb-standoff-assortment-kit-250pcs/ | $15.95
1 | Cable (http://www.crcibernetica.com/apds9960-proximity-light-rgb-and-gesture-sensor-stemma-qt-qwiic/) | CAB-10646 | https://www.crcibernetica.com/ribbon-cable-6-wire-15ft/ | $4.50
1 | STEMMA QT (http://www.crcibernetica.com/apds9960-proximity-light-rgb-and-gesture-sensor-stemma-qt-qwiic/) cable (https://www.crcibernetica.com/m3-nylon-screw-black-hex-screw-nut-nylon-pcb-standoff-assortment-kit-250pcs/) | CAB-CB4925 | https://www.crcibernetica.com/stemma-qt-qwiic-jst-sh-4-pin-cable-20cm/ | $1.95
1 | Interruptor general (https://www.crcibernetica.com/m3-nylon-screw-black-hex-screw-nut-nylon-pcb-standoff-assortment-kit-250pcs/) | AD69986 | https://www.microjpm.com/products/ad69986/ (https://www.crcibernetica.com/ribbon-cable-6-wire-15ft/) | $0.30
1 | Headers macho | AD3780 | https://www.microjpm.com/products/conector-con-dobles-tipo-u-macho-40-pines/ | $1.20
2 | Tornillos M3x10 | AD30202 | https://www.microjpm.com/products/ad30202/ (https://www.microjpm.com/products/ad69986/) | $0.18
1 | Tornillos M2 | AD84286 | https://www.microjpm.com/products/ad84286/ (https://www.microjpm.com/products/conector-con-dobles-tipo-u-macho-40-pines/) | $17.95

Materiales para la construcción de 1 agente de Atta-Bot

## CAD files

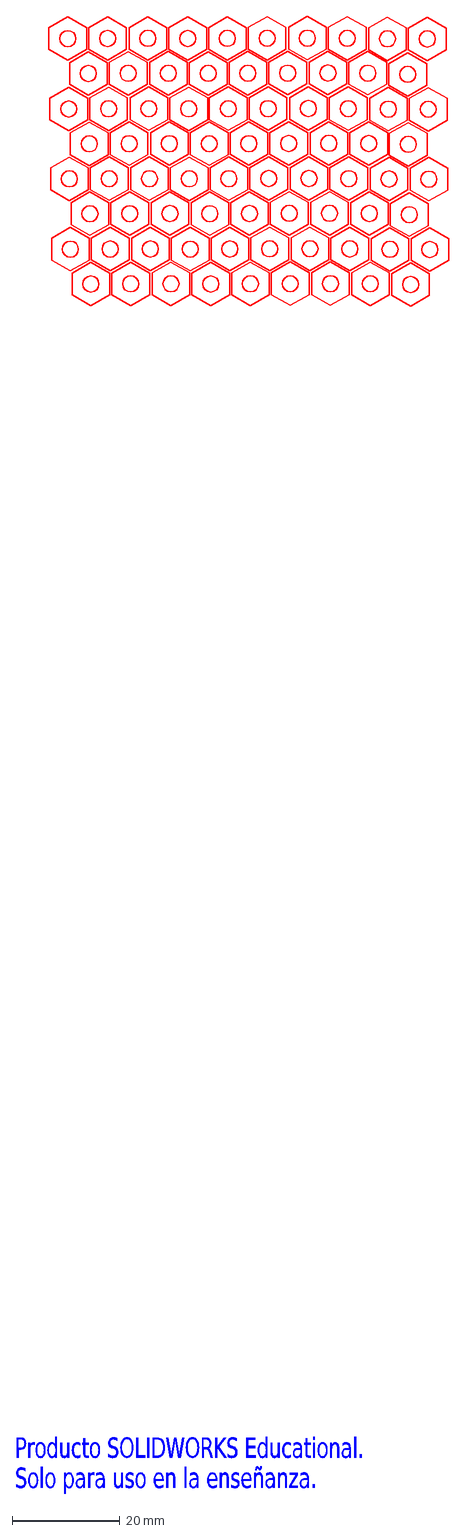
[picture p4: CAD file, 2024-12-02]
Chassis/2D_Files/planosCorte_1.5mm.DXF
Producto SOLIDWORKS Educational.
Solo para uso en la enseñanza.

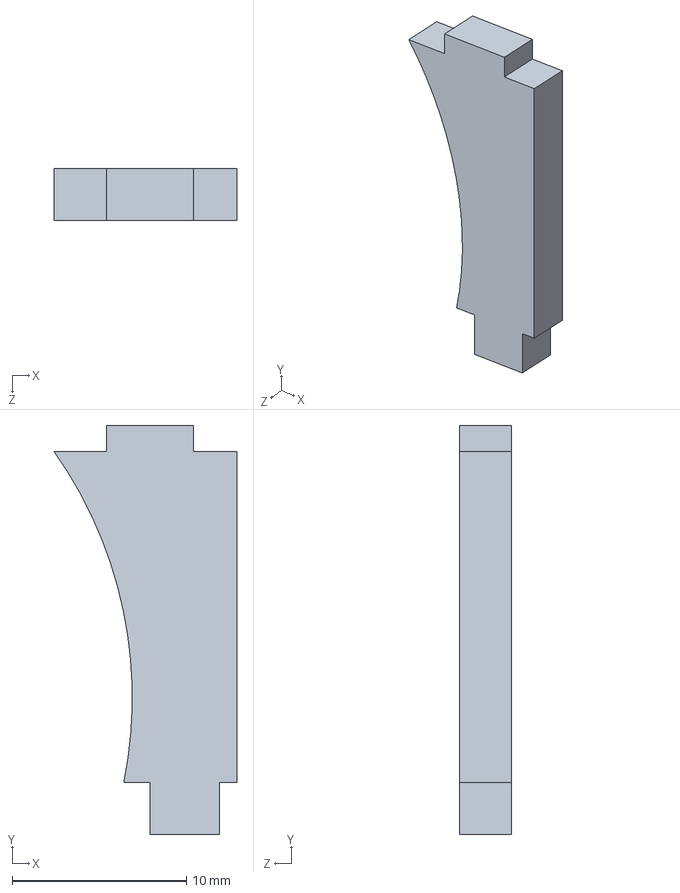
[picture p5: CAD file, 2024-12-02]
Chassis/3D_Files/carcazaLateralFrontal.SLDPRT
10.5 x 23.5 x 3.00 mm

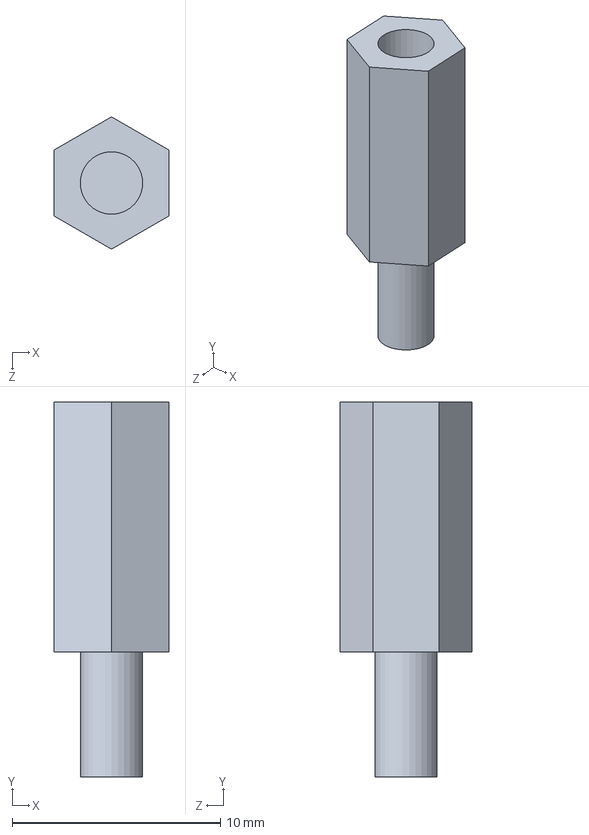
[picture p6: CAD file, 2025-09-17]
Chassis/3D_Files/estandar/espaciador_12mm.SLDPRT
5.50 x 18.0 x 6.35 mm

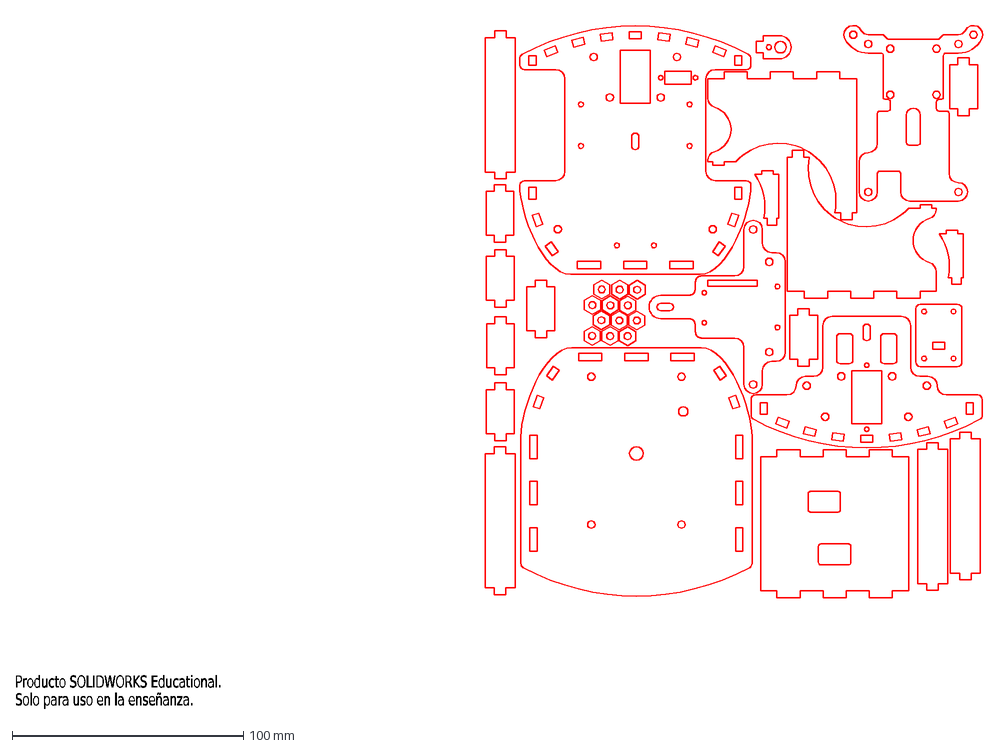
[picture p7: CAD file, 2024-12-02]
Chassis/2D_Files/planosCorte_3mm.DXF
Producto SOLIDWORKS Educational.
Solo para uso en la enseñanza.

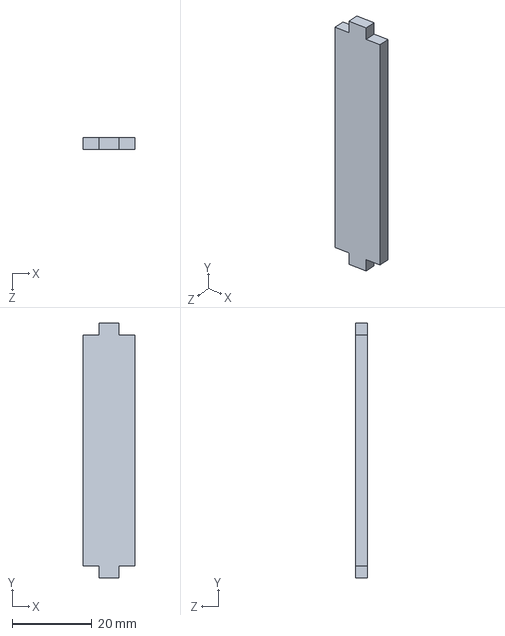
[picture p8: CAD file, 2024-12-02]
Chassis/3D_Files/carcazaLateralTrasera.SLDPRT
13.0 x 64.0 x 3.00 mm

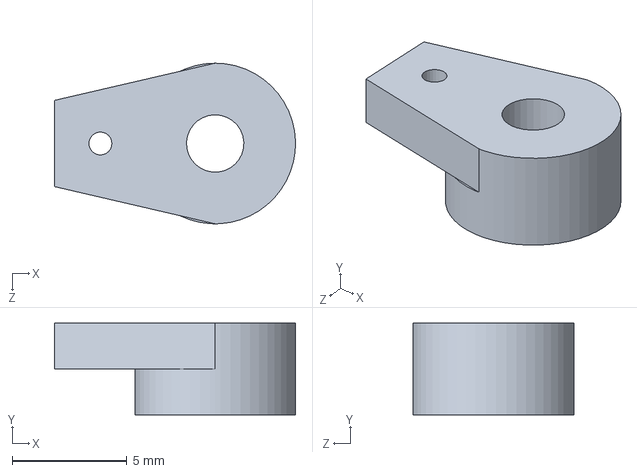
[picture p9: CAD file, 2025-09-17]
Chassis/3D_Files/estandar/micro_servo_arm.SLDPRT
10.5 x 4.00 x 7.00 mm

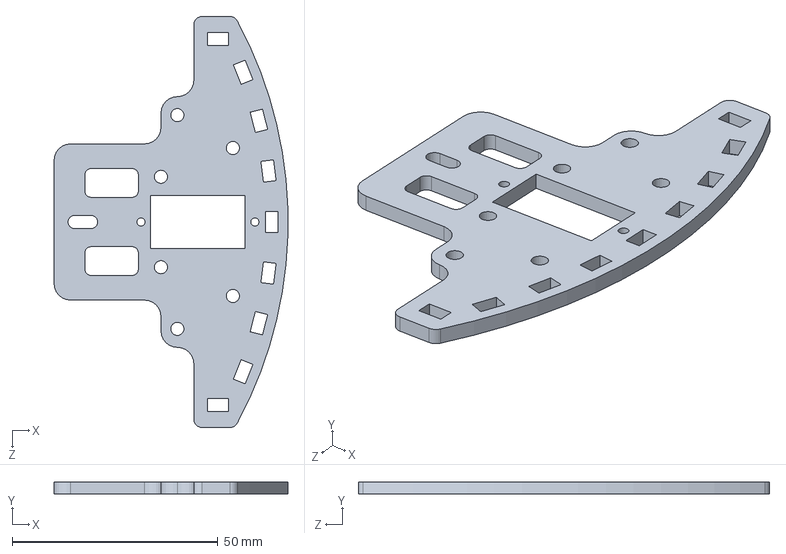
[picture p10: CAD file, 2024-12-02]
Chassis/3D_Files/baseServo.SLDPRT
56.9 x 3.00 x 100.0 mm

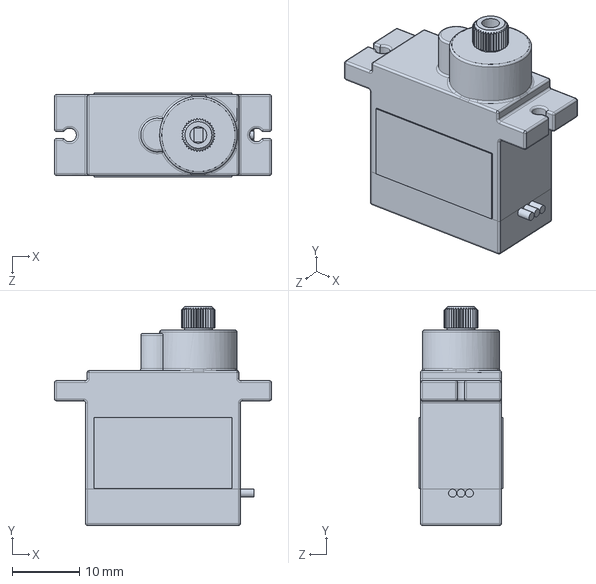
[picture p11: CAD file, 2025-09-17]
Chassis/3D_Files/estandar/MG90S.SLDPRT
32.2 x 32.5 x 12.4 mm

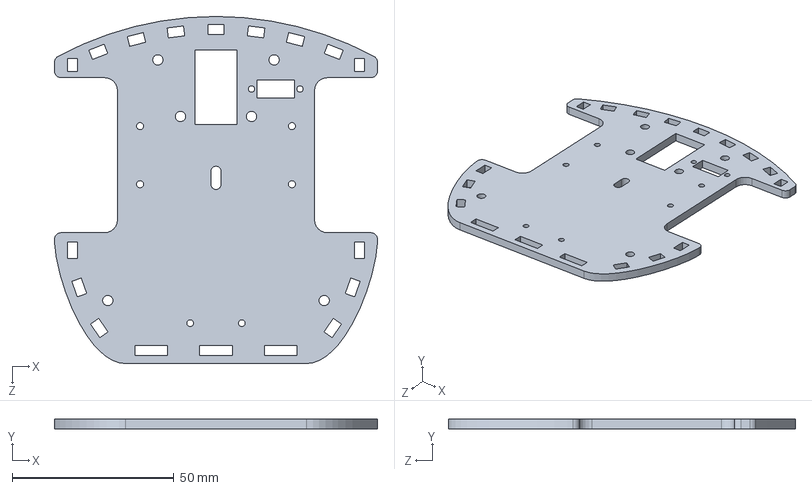
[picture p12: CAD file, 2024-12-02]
Chassis/3D_Files/base.SLDPRT
100.0 x 3.00 x 107.5 mm

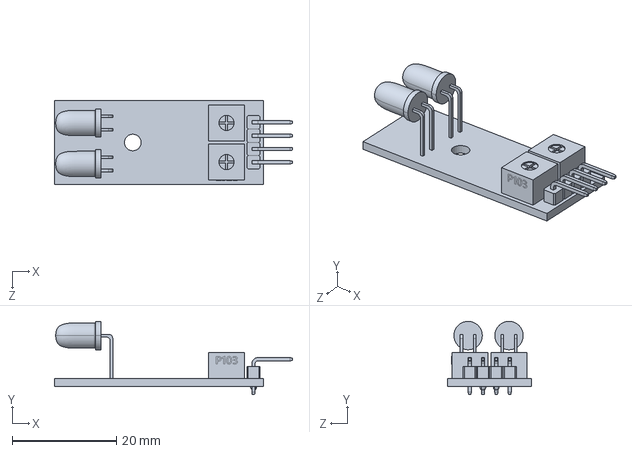
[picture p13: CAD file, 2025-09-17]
Chassis/3D_Files/estandar/IRsensors.SLDPRT
45.6 x 14.0 x 16.0 mm

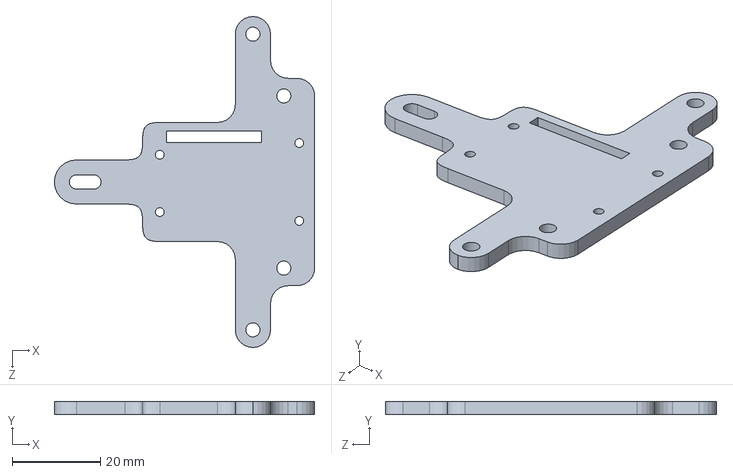
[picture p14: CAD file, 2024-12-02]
Chassis/3D_Files/baseBoost.SLDPRT
59.0 x 3.00 x 75.0 mm

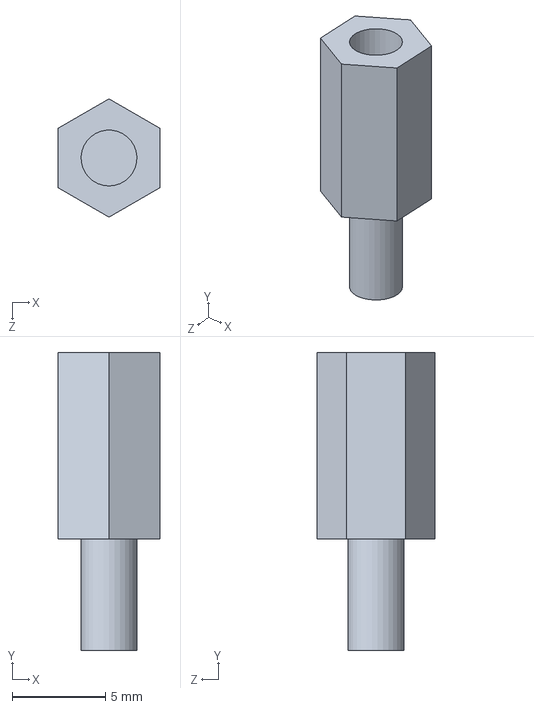
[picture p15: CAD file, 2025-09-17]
Chassis/3D_Files/estandar/espaciador_10mm.SLDPRT
5.50 x 16.0 x 6.35 mm

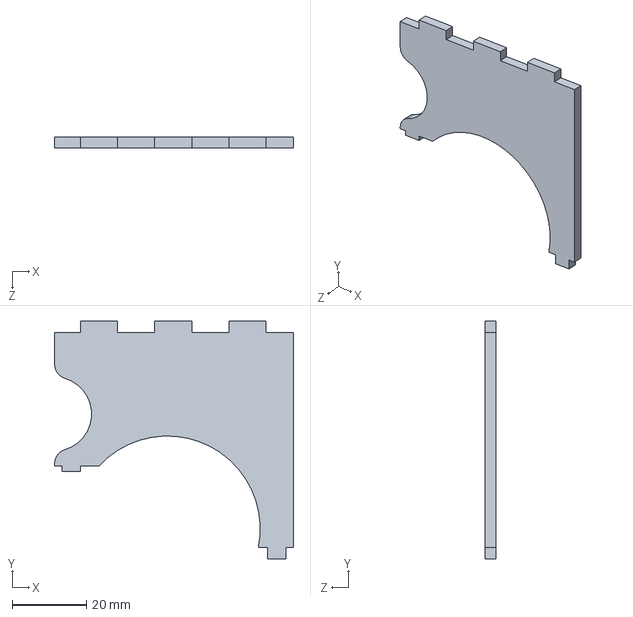
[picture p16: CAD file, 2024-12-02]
Chassis/3D_Files/carcazaLateral.SLDPRT
64.4 x 64.0 x 3.00 mm

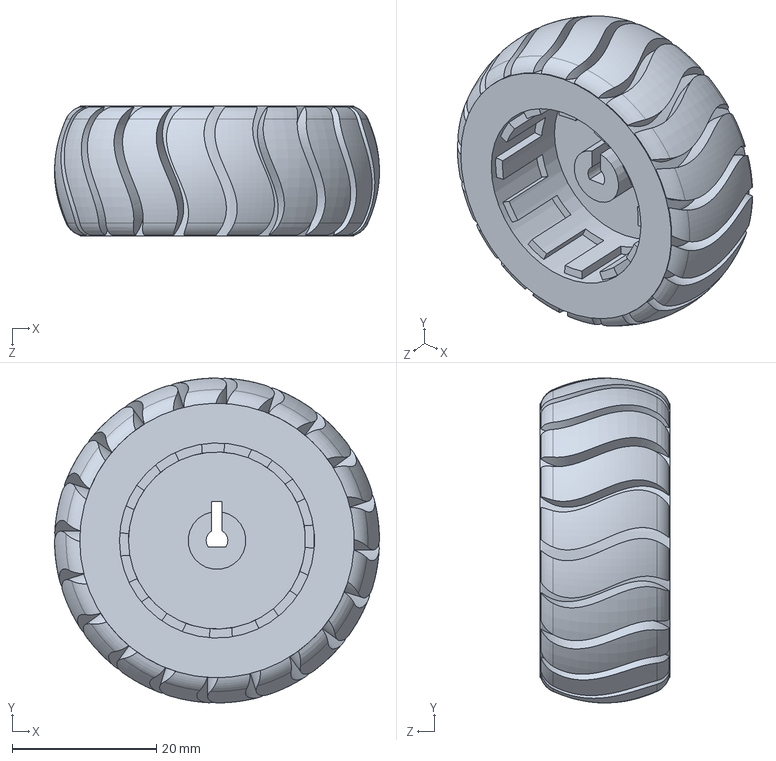
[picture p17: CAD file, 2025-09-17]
Chassis/3D_Files/estandar/ruedaN20.SLDPRT
45.0 x 45.0 x 18.0 mm

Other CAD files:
Docs/SystemVisionIdentifiers.dwg
Chassis/3D_Files/carcazaTrasera.SLDPRT
Chassis/3D_Files/estandar/ideaBoard.SLDPRT
Chassis/3D_Files/baseAPDS2.SLDPRT
Chassis/2D_Files/planosCorte_1.5mm.SLDDRW
Chassis/2D_Files/planosCorte_3mm.SLDDRW
Chassis/3D_Files/baseAPDS1.SLDPRT
Chassis/3D_Files/baseImu.SLDPRT
Chassis/3D_Files/carcazaFrontal.SLDPRT
Chassis/3D_Files/estandar/APDS9960.SLDPRT
Chassis/3D_Files/estandar/LiPoBattery.SLDPRT
Chassis/3D_Files/estandar/bracketN20.SLDPRT
Chassis/3D_Files/estandar/casterBallWheel.SLDPRT
Chassis/3D_Files/estandar/espaciador_1.5mm.SLDPRT
Chassis/3D_Files/estandar/espaciador_15mm.SLDPRT
Chassis/3D_Files/estandar/espaciador_3mm.SLDPRT
Chassis/3D_Files/estandar/espaciador_6mm.SLDPRT
Chassis/3D_Files/estandar/powerboost.SLDPRT
Chassis/3D_Files/estandar/tornilloM3.SLDPRT
Chassis/3D_Files/tapa.SLDPRT

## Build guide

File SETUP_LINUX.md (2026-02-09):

# Guía de Configuración: Atta-Bot en Arch Linux

## 🐧 Migración desde Windows

Este documento cubre los cambios necesarios para ejecutar Atta-Bot en Arch Linux después de trabajar en Windows.

---

## ✅ Cambios Implementados

### 1. **Backend de Cámara Multiplataforma**

El sistema ahora detecta automáticamente:
- **Linux**: `CAP_V4L2` (Video4Linux2)
- **Windows**: `CAP_DSHOW` (DirectShow)
- **macOS**: `CAP_AVFOUNDATION`

**Auto-detección de cámara**: Ya no necesitas hardcodear el índice. El sistema busca automáticamente entre `/dev/video0` - `/dev/video4`.

### 2. **Configuración UDP Mejorada**

- Agregado `SO_REUSEPORT` para Linux (evita "Address already in use")
- Mensajes de error detallados con soluciones
- Validación automática de bind

### 3. **Script de Diagnóstico**

Creado `Base/check_system.py` para verificar:
- Cámaras disponibles
- Interfaces de red
- Puertos UDP
- Permisos de usuario
- Versión de OpenCV

---

## 🚀 Setup Inicial en Arch Linux

### Paso 1: Instalar Dependencias

```bash
# Paquetes del sistema
sudo pacman -S python python-pip python-opencv v4l-utils

# Dependencias Python
cd /home/thrain/Documents/Atta-Bot-P_ed/Base
pip install opencv-python numpy
```

### Paso 2: Verificar Permisos de Cámara

```bash
# Agregar tu usuario al grupo 'video'
sudo usermod -a -G video $USER

# Aplicar cambios (cierra sesión y vuelve a entrar, o ejecuta):
newgrp video

# Verificar que la cámara es accesible
ls -l /dev/video*
```

### Paso 3: Ejecutar Diagnóstico

```bash
cd Base
python3 check_system.py
```

**Ejemplo de salida esperada:**
```
✓ Índice 0: 1920x1080 @ 30 FPS
  Dispositivo: /dev/video0

✓ IP: 192.168.1.100
  Broadcast sugerido: 192.168.1.255

✓ Puerto 6060 disponible
```

### Paso 4: Actualizar `configSystem.json`

Basándote en la salida del script de diagnóstico:

```json
{
  "vision_system": {
    "camera_index": 0,  // <-- Agregar esta línea (opcional)
    "camera_resolution": "1920x1080",
    // ... resto de configuración
  },
  "udp_communication": {
    "base_ip": "192.168.1.100",      // <-- Tu IP en Linux
    "broadcast_ip": "192.168.1.255",  // <-- Broadcast de tu red
    "port": 6060
  }
}
```

**Nota**: Si omites `camera_index`, el sistema auto-detectará la primera cámara disponible.

---

## 🔧 Solución de Problemas Comunes

### ❌ Error: "No se pudo abrir la cámara"

**Solución 1**: Verificar que existe
```bash
ls /dev/video*
v4l2-ctl --list-devices
```

**Solución 2**: Verificar permisos
```bash
# Debe mostrar crw-rw----+ 1 root video
ls -l /dev/video0

# Si no tienes permisos:
sudo usermod -a -G video $USER
newgrp video
```

**Solución 3**: Probar índice diferente
```bash
python3 check_system.py  # Te dirá qué índices están disponibles
```

---

### ❌ Error: "Address already in use" (Puerto UDP)

**Causa**: El puerto 6060 está en uso o no se liberó después de Ctrl+C.

**Solución 1**: Esperar 60 segundos (timeout de `TIME_WAIT`)

**Solución 2**: Verificar qué proceso lo usa
```bash
sudo netstat -tulpn | grep 6060
# o
sudo lsof -i :6060
```

**Solución 3**: Matar proceso anterior
```bash
# Si ves PID en la salida anterior:
kill -9 <PID>
```

**Solución 4**: Cambiar puerto temporalmente en `configSystem.json`
```json
"port": 6061
```

---

### ❌ Error: "No module named 'cv2'"

```bash
# Opción 1: pip del sistema
sudo pacman -S python-opencv

# Opción 2: pip de usuario
pip install opencv-python

# Opción 3: entorno virtual (recomendado)
python -m venv venv
source venv/bin/activate
pip install opencv-python numpy
```

---

### ❌ Cámara detectada pero imagen negra

**Causa**: La cámara puede estar en uso por otra aplicación (Zoom, Teams, etc.)

```bash
# Verificar aplicaciones usando la cámara
lsof /dev/video0

# Cerrar aplicaciones y reintentar
```

---

### ❌ ESP32 no se conectan a WiFi

**Verificación en Linux**:
```bash
# Ver dispositivos conectados a tu red
sudo nmap -sn 192.168.1.0/24

# Escuchar broadcasts UDP (en otra terminal)
sudo tcpdump -i wlan0 udp port 6060
```

**Checklist**:
1. ✓ ESP32 y PC en la misma red WiFi
2. ✓ SSID y contraseña correctos en `AttaBot.ino`
3. ✓ Firewall no bloquea UDP 6060:
   ```bash
   sudo ufw allow 6060/udp
   # o
   sudo iptables -A INPUT -p udp --dport 6060 -j ACCEPT
   ```

---

## 📊 Diferencias Windows vs Linux

| Aspecto | Windows | Linux (Arch) |
|---|---|---|
| Backend cámara | `CAP_DSHOW` | `CAP_V4L2` |
| Dispositivo cámara | Índice numérico | `/dev/videoX` |
| Socket UDP | `SO_REUSEADDR` | `SO_REUSEADDR` + `SO_REUSEPORT` |
| Permisos cámara | No requeridos | Grupo `video` |
| Rutas archivos | `\` | `/` (ya soportado con `os.path.join`) |

---

## 🧪 Prueba Rápida del Sistema

### 1. Verificar Cámara
```bash
cd Base
python3 check_system.py
```

### 2. Probar Captura de Video
```bash
cd Base
python3 -c "import cv2; cap = cv2.VideoCapture(0, cv2.CAP_V4L2); print('OK' if cap.isOpened() else 'FAIL'); cap.release()"
```

### 3. Ejecutar Sistema Base
```bash
cd Base
python3 AttaBot_Base.py
```

**Salida esperada:**
```
Detectando cámara en Linux...
✓ Cámara encontrada en índice 0
Backend de cámara: 4 (índice 0)
✓ SO_REUSEPORT habilitado (Linux)
✓ Socket UDP bind exitoso en 192.168.1.100:6060
Cantidad de robots en la prueba:
```

---

## 🎯 Tips para Arch Linux

### Optimizar Latencia de Cámara

```bash
# Deshabilitar buffering de V4L2
v4l2-ctl -d /dev/video0 --set-ctrl=video_bitrate=25000000
```

### Firewall (UFW)

```bash
# Permitir tráfico local
sudo ufw allow from 192.168.1.0/24 to any port 6060 proto udp
```

### Rendimiento

Si experimentas lag en el sistema de visión:

```python
# En AttaBot_Base.py, reducir calidad de video
self.camera.set(cv2.CAP_PROP_BUFFERSIZE, 1)  # Agregar después de línea 780
```

---

## 📝 Notas Finales

### Auto-detección vs Manual

**Auto-detección** (recomendado):
- Omite `camera_index` en `configSystem.json`
- El sistema encuentra la primera cámara disponible

**Manual** (para múltiples cámaras):
```json
"camera_index": 2  // Si tienes webcam en 0, otra en 1, y quieres la de índice 2
```

### Calibración de Cámara

Los archivos de calibración (`cameraMatrix.txt`, `distance.txt`) son compatibles entre Windows y Linux. **No necesitas recalibrar**.

---

## 🆘 Ayuda Adicional

Si sigues teniendo problemas:

1. Ejecuta el diagnóstico completo:
   ```bash
   python3 Base/check_system.py > diagnostico.txt
   ```

2. Revisa los logs con más detalle ejecutando con Python en modo verbose:
   ```bash
   python3 -v Base/AttaBot_Base.py
   ```

3. Verifica versiones:
   ```bash
   python --version
   python -c "import cv2; print(cv2.__version__)"
   ```

---

**Última actualización**: 2025-12-02
**Sistema probado**: Arch Linux (kernel 6.12.59-1-lts)

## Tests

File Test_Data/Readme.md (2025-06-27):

Test data from validation and experiments

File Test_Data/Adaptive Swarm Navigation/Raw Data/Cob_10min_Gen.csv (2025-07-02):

Rob | Time | Percent | Dist_1 | Pel_1 | CobGen_1 | Cob_1 | Dist_2 | Pel_2 | CobGen_2 | Cob_2 | Dist_3 | Pel_3 | CobGen_3 | Cob_3 | Dist_4 | Pel_4 | CobGen_4 | Cob_4 | Dist_5 | Pel_5 | CobGen_5 | Cob_5 | Dist_6 | Pel_6 | CobGen_6 | Cob_6 | Dist_7 | Pel_7 | CobGen_7 | Cob_7 | Dist_8 | Pel_8 | CobGen_8 | Cob_8 | Dist_9 | Pel_9 | CobGen_9 | Cob_9 | Dist_10 | Pel_10 | CobGen_10 | Cob_10 | Dist_11 | Pel_11 | CobGen_11 | Cob_11 | Dist_12 | Pel_12 | CobGen_12 | Cob_12 | Dist_13 | Pel_13 | CobGen_13 | Cob_13 | Mean_Dist | STD_Dist | Mean_Pel | STD_Pel | Mean
1 | 0.0 | 0.0 | 56.56854249492381 | 1.06 | 10 | 1.841620626151013 | 76.5685424949238 | 0.5499999999999999 | 8 | 1.4732965009208103 | 48.2842712474619 | 0.4499999999999999 | 6 | 1.1049723756906076 | 48.2842712474619 | 0.4499999999999999 | 6 | 1.1049723756906076 | 48.2842712474619 | 0.365 | 8 | 1.4732965009208103 | 48.2842712474619 | 0.4499999999999999 | 6 | 1.1049723756906076 | 48.2842712474619 | 0.705 | 6 | 1.1049723756906076 | 48.2842712474619 | 0.4499999999999999 | 6 | 1.1049723756906076 | 48.2842712474619 | 0.365 | 8 | 1.4732965009208103 | 48.2842712474619 | 0.93 | 7 | 1.289134438305709 | 48.2842712474619 | 0.93 | 6 |
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

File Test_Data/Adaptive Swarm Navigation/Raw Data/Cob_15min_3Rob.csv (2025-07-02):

Prueb | Time | Cob | Cob_Porc
1 | 0.0 | 21 | 3.867403314917127
1 | 0.16666666666666666 | 21 | 3.867403314917127
1 | 0.3333333333333333 | 23 | 4.23572744014733
1 | 0.5166666666666667 | 68 | 12.52302025782689
1 | 0.6833333333333333 | 75 | 13.812154696132598
1 | 0.85 | 97 | 17.863720073664823
1 | 1.0166666666666666 | 123 | 22.65193370165746
1 | 1.1833333333333333 | 130 | 23.941068139963168
1 | 1.35 | 179 | 32.96500920810313
1 | 1.5166666666666666 | 209 | 38.48987108655617
1 | 1.6833333333333333 | 225 | 41.43646408839779
1 | 1.85 | 245 | 45.11970534069982
1 | 2.0166666666666666 | 246 | 45.30386740331492
1 | 2.2 | 248 | 45.67219152854512
1 | 2.3666666666666667 | 251 | 46.224677716390424
1 | 2.533333333333333 | 254 | 46.77716390423573
1 | 2.7 | 273 | 50.27624309392266
1 | 2.8666666666666667 | 279 | 51.38121546961326
1 | 3.033333333333333 | 289 | 53.22283609576427
1 | 3.2 | 315 | 58.011049723756905
1 | 3.3666666666666667 | 338 | 62.246777163904234
1 | 3.533333333333333 | 346 | 63.72007366482505
1 | 3.7 | 349 | 64.27255985267035
1 | 3.8833333333333333 | 350 | 64.45672191528546
1 | 4.05 | 373 | 68.69244935543279
1 | 4.216666666666667 | 390 | 71.8232044198895
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

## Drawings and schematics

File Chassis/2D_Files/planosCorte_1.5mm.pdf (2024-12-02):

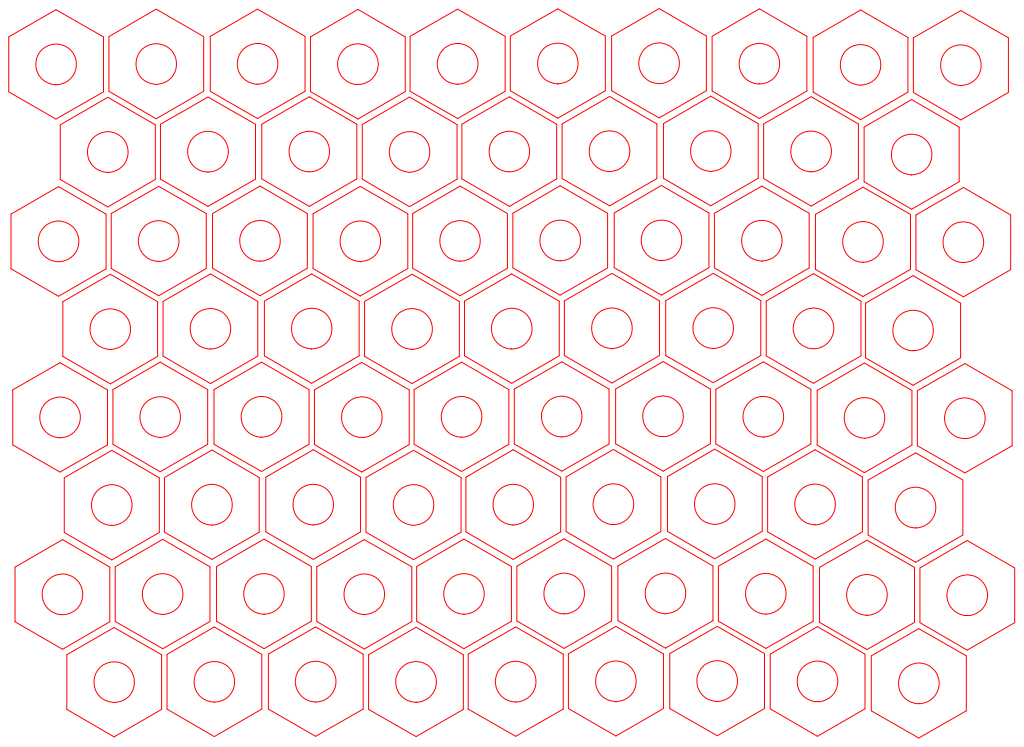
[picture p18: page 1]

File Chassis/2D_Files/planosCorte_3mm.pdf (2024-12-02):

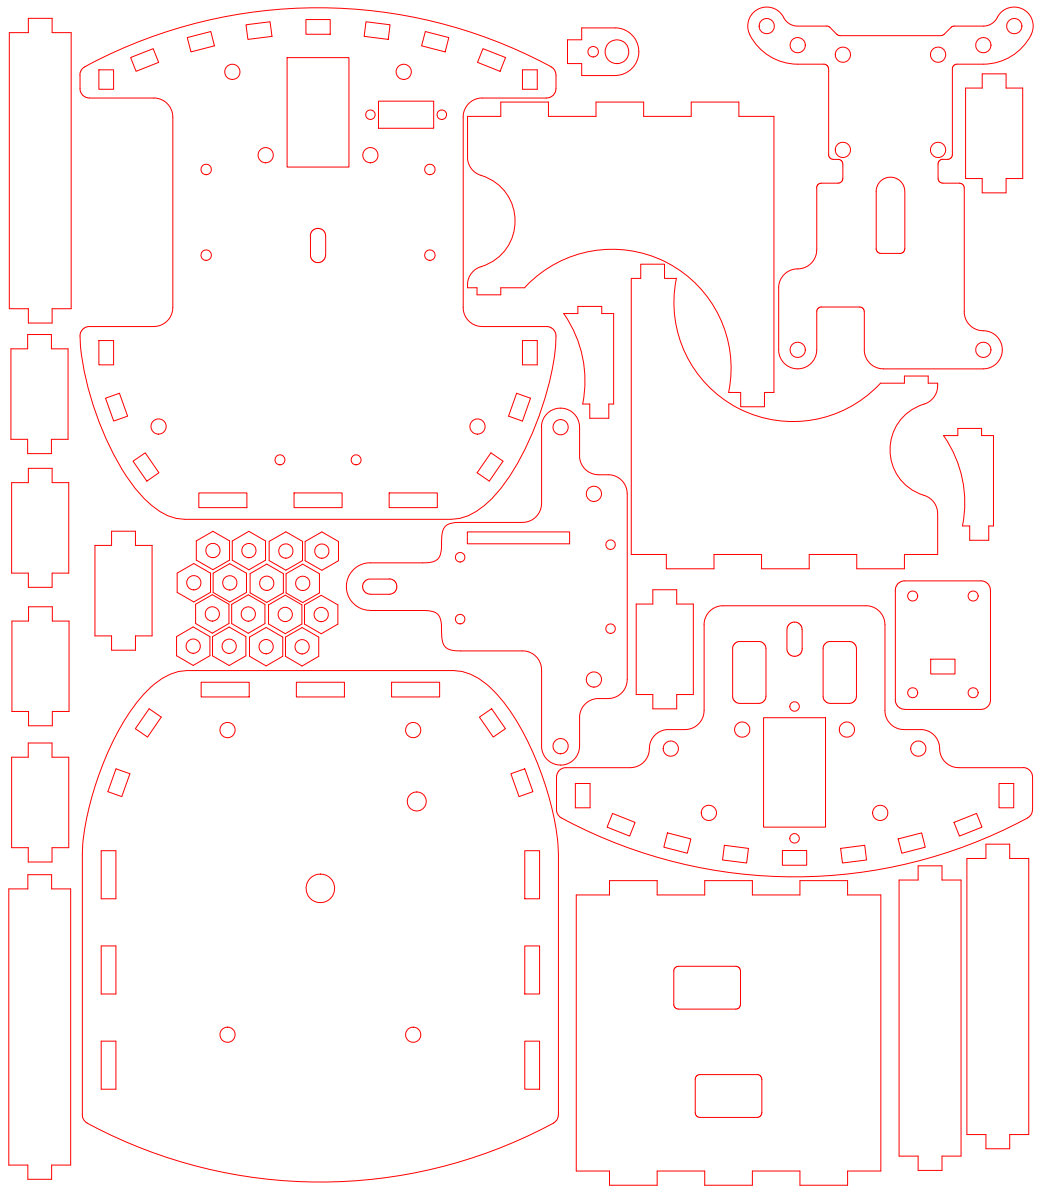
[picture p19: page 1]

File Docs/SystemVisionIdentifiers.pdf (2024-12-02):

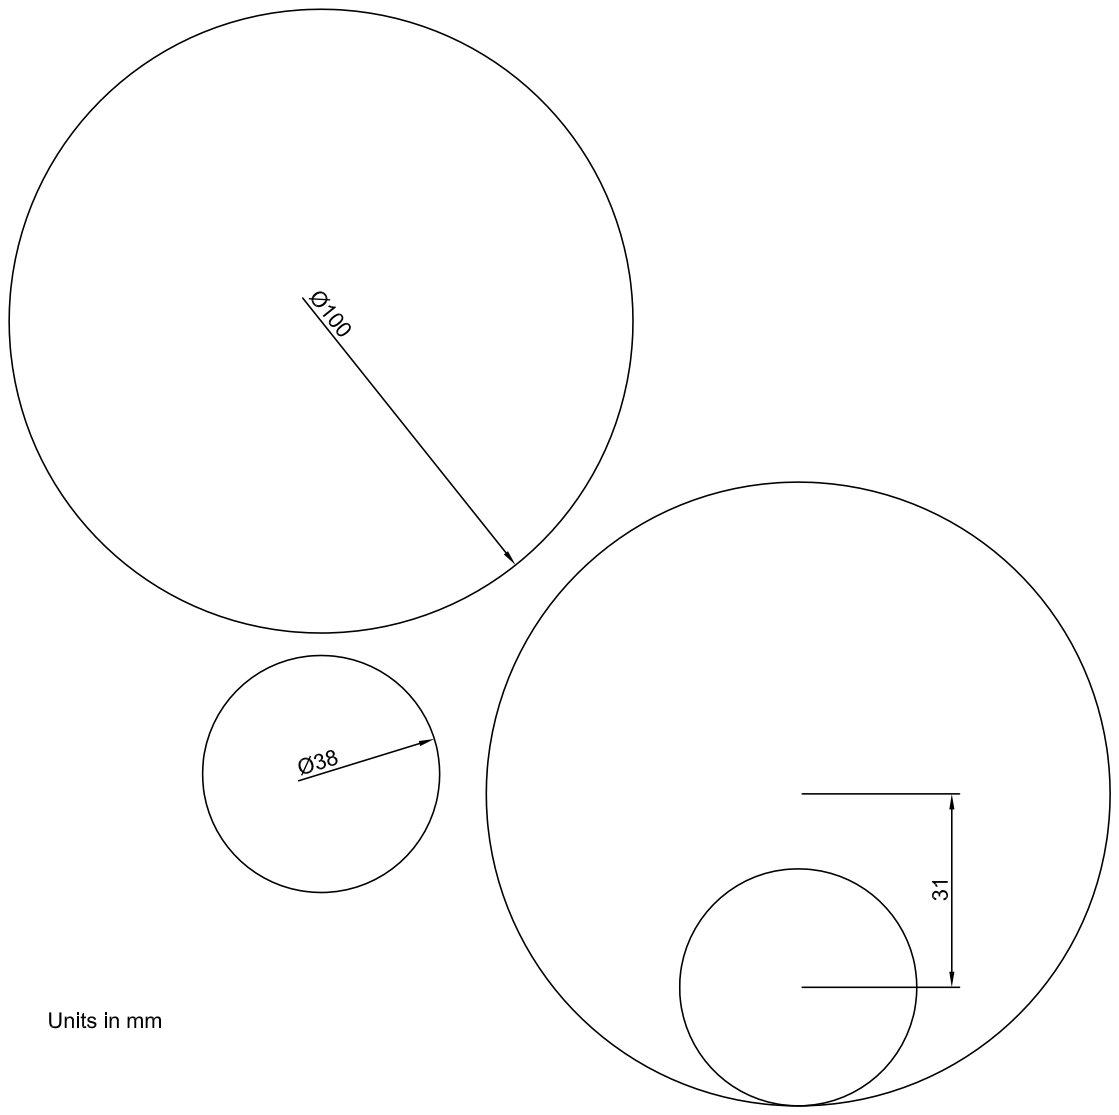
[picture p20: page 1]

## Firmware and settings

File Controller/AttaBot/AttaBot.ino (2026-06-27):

#include "utils.h"
#include <Adafruit_APDS9960.h> // v1.3.0
#include <ArduinoOTA.h>
#include <ESP32Servo.h> // v3.0.9
#include <FastLED.h>    // v3.10.2
#include <ICM_20948.h>  // v1.2.12
#include <Preferences.h>
#include <WiFi.h>
#include <WiFiUdp.h>
#include <Wire.h>

// ============================================================================
// CONFIGURACIÓN DE DEBUG
// ============================================================================

// Descomentar solo para debug
#define DebugSerial
#ifdef DebugSerial
#define DebugSerialPrint(x) Serial.print(x)
#define DebugSerialPrintln(x) Serial.println(x)
#define DebugSerialPrintf(x, ...) Serial.printf(x, ##__VA_ARGS__)
#else
#define DebugSerialPrint(x)
#define DebugSerialPrintln(x)
#define DebugSerialPrintf(x, ...)
#endif

// ============================================================================
// DEFINICIÓN DE PINES
// ============================================================================

#define leftMotorForward 12
#define leftMotorBackward 14
#define rightMotorForward 13
#define rightMotorBackward 15

#define leftEncoderC1 32
#define leftEncoderC2 35
#define rightEncoderC1 23
#define rightEncoderC2 25

#define enableLeftInfraredSensor 5
#define leftInfraredSensor 33
#define frontServoPin 26
#define enableRightInfraredSensor 18
#define rightInfraredSensor 27

#define batteryStatus 19
#define ledPin 2
#define AD0_VAL 1
#define NUM_LEDS 1

#define pwm_freq 1000
#define pwm_resolution 14

// ============================================================================
// CONSTANTES DEL SISTEMA
// ============================================================================

// WiFi
const char *ssid = "Atta-Bot";
const char *password = "attabot1234";
const unsigned int localPort = 6060;
char receivedPacket[255];

// Constantes del robot
float pulsesPerRev = 574;
const float wheelCircumference = PI * 44.5;
float millimetersPerPulse = wheelCircumference / pulsesPerRev;
float centerToWheelDistance = 41.5;  // configurable vía NAV_CONFIG|WHEEL_DIST
float yawScale = 1.0f;  // escala del gyro por robot (físico/IMU, calibrada con
                        // ArUco; ±2.4% medido) — NAV_CONFIG|YAW_SCALE|x|SAVE

// Muestreo y velocidad
const unsigned int samplingTime = 10;
const float samplingTimeS = samplingTime * 0.001;
const unsigned int SteadyStateTime = 800;
const float distanceOffset = 1 * millimetersPerPulse;
const float baseSpeed = millimetersPerPulse / samplingTimeS;
const float maxSpeed = baseSpeed * 5;
const float minSpeed = 12;
const int speedReductionThreshold = 16;

// Control PID
const int maxPWMValue = (1 << pwm_resolution) - 1;
const int minPWMValue = maxPWMValue * 0.20;
pidConstants pidSpeed(110, 375, 2);
kalmanFilter kfPID(6.0, 1.0, 1.0);

// Sensores de obstáculos
const int observationPeriod = 28800;
const int observationTime = 1600;
const int numberOfCycles = observationPeriod / observationTime;
const int lateralCycle = random(numberOfCycles);
const int centralCycle =
    (lateralCycle + random(1, numberOfCycles)) % numberOfCycles;
const unsigned minObstacleTime = 1350;

// Detección de robots
const float robotDistanceMargin = 260;
const float maxRobotAngleMargin = 80;
const int obstacleWaitTime = 600;
const int reverseDistance = -40;

// Debug
int debugUdp = 0;
int debugCounter = 0;
char direction = '+';
const char *debugMessage =
    "DEBUG: %d, ID: %s, Direccion: %c, val: Izq|Der, Encoder: %d|%d, Vel: "
    "%.2f|%.2f, Pwm: %d|%d, ErrorP: %.2f|%.2f, ErrorI: %.2f|%.2f, Dis: "
    "%.2f|%.2f, Tiempo: %d";

// Random Walk
const std::array<int, 7> possibleAngles = {30, 45, 60, 75, 90, 135, 180};
const std::array<int, 4> possibleAdvances = {200, 250, 300, 350};
enum possibleDirections { TURN_POS = 0, MOVE_FORWARD, TURN_NEG };

// Límites del área de trabajo (en milímetros)
const float max_workspace_x = 2000;
const float max_workspace_y = 2000;

// Filtro de saltos bruscos en actualización de pose
const float max_pose_jump =
    500; // Máximo salto permitido en mm por actualización
const float max_angle_jump = 179; // Máximo salto permitido en grados
const int max_pose_jump_rejections =
    3; // Rechazos consecutivos antes de re-sincronizar con la cámara
int poseJumpRejections = 0;

// IMU
const float gravity = 9806.65;
const float conversionFactor = 8192.0;
float yaw;
float imuGravity;
bool imuAvailable = false;  // true solo si setupIMU() completó exitosamente

// LEDs
int maxBrightness = 140;

// Batería
volatile unsigned long lowBatteryTime = 0;
int minLowBatteryTime = 200;

// Contador de mensajes
int countMessages = 0;
int sendMessages = 0;

// Servo
bool frontSensorInitialized = false;
unsigned long lastFrontSensorAttempt = 0;
const unsigned long frontSensorRetryInterval =
    5000; // Reintentar cada 5 segundos
volatile bool lateralSensorsEnabled = false;

// ============================================================================
// VARIABLES GLOBALES REFACTORIZADAS (usando estructuras de utils.h)
// ============================================================================

NavigationTarget navTarget;
InterruptionContext intContext;
EvasionTracker evasionTracker;
CongregationState congregation;
ObstacleState obstacles;
MovementMetrics movement;
LedController ledCtrl;
Bug2State bug2;
AutotuneState atState;

// IMU — control de frecuencia de lectura
unsigned long lastImuRead = 0;
const unsigned long imuReadInterval = 20;  // ms — 50Hz, por debajo del ODR del DMP (~112Hz)

// Variables de control de movimiento
unsigned long currentMillis = millis();
unsigned long previousMillisRW = 0;
int millisDifference;
int pastLeftEncoder = 0;
int pastRightEncoder = 0;

// Variables de sensores
unsigned long currentMicros = micros();
unsigned long previousMicros = micros();
bool isLateralCycleActive = false;
bool isCentralCycleActive = false;
// Máscaras de sensores IR — true = ignorar ese sensor (SENSOR_MASK|L/R/C|1)
bool maskLeftIR = false;
bool maskRightIR = false;
bool maskCentralIR = false;
int cycleCounter = 0;
int microsDifference;
volatile unsigned long leftObsStartTime = 0;
volatile unsigned long rightObsStartTime = 0;
unsigned long centralObsStartTime = 0;
int centralDistance;

// Estado del robot
String robotID = "-1";
std::map<String, IPAddress> robots;
RobotState state = WAIT;
float instructionValue = 100;
bool movementReady = true;

// Navegación reactiva unificada (GT + congregación)
ReactiveNav nav;

// IMU-assisted TURN: giro cerrado en yaw — el arco restante se re-apunta con
// el IMU en cada ciclo, y al final se corrige si quedó residuo
bool  imuTurnActive   = false;
bool  imuTurnIsCorrection = false;  // el residuo se cierra SIN brake-lead (lead=0);
                                    // si no, en arcos chicos el coast reservado se
                                    // come la corrección entera (cmd -5.3° → real 0.8°)
int   imuTurnCorrCount = 0;         // correcciones hechas en este giro (tope: imuTurnMaxCorrections)
float imuTurnStartYaw = 0.0f;
float imuTurnPrevYaw  = 0.0f;    // última lectura para unwrap incremental
float imuTurnAccumDeg = 0.0f;    // giro acumulado medido por IMU (sin wrap, soporta >180°)
float imuTurnTargetDeg = 0.0f;   // ángulo objetivo con signo (+ = CCW, - = CW)
unsigned long imuTurnSettleUntil = 0;  // !=0: motores cortados, midiendo coast
const float imuTurnBrakeLead = 3.0f;   // cortar motores N° antes: la inercia
                                       // (coast, 2-12° medido vs ArUco) completa el giro
const unsigned long imuTurnSettleMs = 400;  // ventana para que el coast termine
                                            // antes de la verificación final
const float imuTurnTolerance = 3.0f;   // residuo bajo el cual el giro se da por bueno;
                                       // con corrección iterativa ahora sí aterriza acá
const int imuTurnMaxCorrections = 4;   // tope de correcciones por giro — evita
                                       // perseguir el ruido del gyro indefinidamente
const int instructionCompletedDelay = 400;
std::array<float, 2> fsmInstruction;
std::deque<std::array<float, 2>> instructionList;
pose robotPose(0, 0, 0);

// Evasión
bool isEvading = false;
unsigned long evasionStartTime = 0;
const unsigned long evasionCooldown = 2000;
bool resumeScheduled = false;
bool obstacleDetected = false;

// Controladores PID
pidController leftControl(kfPID, pidSpeed, samplingTimeS, minPWMValue,
                          maxPWMValue);
pidController rightControl(kfPID, pidSpeed, samplingTimeS, minPWMValue,
                           maxPWMValue);

// Hardware
Servo frontServo;
Adafruit_APDS9960 frontSensor;
CRGB leds[NUM_LEDS];
WiFiUDP udp;
ICM_20948_I2C imu;
Preferences preferences;

// ============================================================================
// DECLARACIONES FORWARD DE FUNCIONES
// ============================================================================

// Setup y configuración
void SetupFrontSensor();
void WiFiStatus();
void updateMillimetersPerPulse();
void InitializePPR();
void SavePPR(float newPPR);
void InitializePID();
void SavePID(float kp, float ki, float kd);

// Comunicación
void ReadUdpPackets();
void SendMessage(IPAddress host, const char *message);
void SendPose();
void MessageDebugf(const char *format, ...);
void CommunicationTest();

// Sensores y control
void ReadSensors();
void ResetPID();
void ConfigureHBridge(int leftWheelPWM, int rightWheelPWM);

// Movimiento
bool MoveDistanceByWheel(float leftDistance, float rightDistance);
float DesiredSpeed(float distance, float wheelDistance);
void RunAutotune();
void FinishAutotune();
bool IsStationary(float currentLeftSpeed, float currentRightSpeed,
                  float leftWheelDistance, float rightWheelDistance);
void SelectMovementRW();

// Navegación GT (Bug2 unificado)
void InitiateBug2Navigation(float targetX, float targetY);
void EnqueueNavStep(float targetX, float targetY, float maxSeg);
void Bug2ProcessPosition();
void Bug2WallFollowStep();

// Auxiliares
std::array<String, 5> SeparateCommand(const String &command, char delimiter);
bool IsRobotObstacle(float x2, float y2, float angle, int sensors, String id);
void ReadSerialCommands();
// Nota: CalculateDistance, NormalizeAngle e InRange están definidas inline en utils.h
// Se redeclaran aquí para garantizar visibilidad desde este translation unit
inline float CalculateDistance(float x1, float y1, float x2, float y2);
inline float CalculateAngleToTarget(float x1, float y1, float x2, float y2);
inline float NormalizeAngle(float angle);

// LED
void setLedColor(uint8_t red, uint8_t green, uint8_t blue);
void setLedBrightness(uint8_t brightness);
void setLedBlink(uint8_t red, uint8_t green, uint8_t blue,
                 unsigned long intervalMs);

// IMU
void setupIMU();
void SaveIMUBias(biasStore* store);
void LeerYaw();

// ============================================================================
// INTERRUPCIONES (ISR)
// ============================================================================

void i2cScan() {
  Serial.println("\n=== I2C SCAN ===");
  int found = 0;
  for (byte addr = 1; addr < 127; addr++) {
    Wire.beginTransmission(addr);
    byte error = Wire.endTransmission();
    if (error == 0) {
      Serial.printf("  Dispositivo en 0x%02X", addr);
      if (addr == 0x68) Serial.print("  ← IMU (AD0=GND)");
      if (addr == 0x69) Serial.print("  ← IMU (AD0=VCC)");
      if (addr == 0x39) Serial.print("  ← APDS9960");
      Serial.println();
      found++;
    }
  }
  Serial.printf("  Total: %d dispositivo(s)\n", found);
  Serial.println("================\n");
}

void IRAM_ATTR LeftWheelPulses() {
  int MSB = digitalRead(leftEncoderC2);
  int LSB = digitalRead(leftEncoderC1);
  int encoder = (MSB << 1) | LSB;
  int sum = (pastLeftEncoder << 2) | encoder;
  if (sum == 0b1101 || sum == 0b0100 || sum == 0b0010 || sum == 0b1011) {
    movement.leftPulseCount++;
  } else if (sum == 0b1110 || sum == 0b0111 || sum == 0b0001 || sum == 0b1000) {
    movement.leftPulseCount--;
  }
  pastLeftEncoder = encoder;
}

void IRAM_ATTR RightWheelPulses() {
  int MSB = digitalRead(rightEncoderC1);
  int LSB = digitalRead(rightEncoderC2);
  int encoder = (MSB << 1) | LSB;
  int sum = (pastRightEncoder << 2) | encoder;
  if (sum == 0b1101 || sum == 0b0100 || sum == 0b0010 || sum == 0b1011) {
    movement.rightPulseCount++;
  } else if (sum == 0b1110 || sum == 0b0111 || sum == 0b0001 || sum == 0b1000) {
    movement.rightPulseCount--;
  }
  pastRightEncoder = encoder;
}

void IRAM_ATTR DetectLeftObstacle() {
  if (lateralSensorsEnabled && digitalRead(leftInfraredSensor) == LOW) {
    leftObsStartTime = micros();
  }
}

void IRAM_ATTR DetectRightObstacle() {
  if (lateralSensorsEnabled && digitalRead(rightInfraredSensor) == LOW) {
    rightObsStartTime = micros();
  }
}

void LowBattery() {
  if (digitalRead(batteryStatus) == LOW) {
    lowBatteryTime = millis();
  }
}

// ============================================================================
// FUNCIONES DE SETUP Y CONFIGURACIÓN
// ============================================================================
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
void loop() {
  ledCtrl.update();
  WiFiStatus();
  if (WiFi.status() != WL_CONNECTED)
    return;
  ReadUdpPackets();
  ReadSensors();
  SetupFrontSensor();

  // Lectura IMU no bloqueante — se ejecuta solo si la IMU está disponible
  // y han pasado al menos imuReadInterval ms desde la última lectura.
  if (imuAvailable && (millis() - lastImuRead >= imuReadInterval)) {
    lastImuRead = millis();
    LeerYaw();
  }

#ifdef DebugSerial
  ReadSerialCommands();
#endif

  switch (state) {
  case WAIT: {
    ArduinoOTA.handle();

    if ((millis() - movement.previousMillis) >= instructionValue) {
      movement.previousMillis = millis();
      ResetPID();
      if (movementReady) {
        state = READ_INSTRUCTION;
      } else {
        direction = '-';
        state = REVERSE;
      }
    }

    break;
  }

  case MOVE: {
    movementReady = MoveDistanceByWheel(instructionValue, instructionValue);

    if (movementReady) {
      MessageDebugf("DEBUG: -1, ID: %s, Movimiento completado",
                    robotID.c_str());
      intContext.Clear();
      isEvading = false;
      state = STOP;

    } else if (obstacles.HasAnyObstacle() && !isEvading) {
      obstacles.UpdateBitmap();

      intContext.wasInterrupted = true;
      intContext.previousState = MOVE;
      intContext.leftPulsesBeforeStop = movement.pastLeftPulseCount;
      intContext.rightPulsesBeforeStop = movement.pastRightPulseCount;

      float avgTraveled =
          (movement.pastLeftPulseCount + movement.pastRightPulseCount) / 2.0 *
          millimetersPerPulse;
      intContext.remainingValue = instructionValue - avgTraveled;

      isEvading = true;
      evasionStartTime = millis();

      MessageDebugf("DEBUG: -1, ID: %s, MOVE interrumpido: restante=%.1fmm",
                    robotID.c_str(), intContext.remainingValue);

      state = STOP;
    }

    break;
  }

  case TURN: {
    // Capturar yaw inicial la primera vez que se entra al estado
    if (imuAvailable && !imuTurnActive) {
      imuTurnActive      = true;
      imuTurnStartYaw    = yaw;
      imuTurnPrevYaw     = yaw;
      imuTurnAccumDeg    = 0.0f;
      imuTurnSettleUntil = 0;
      imuTurnTargetDeg = (instructionValue / centerToWheelDistance) * RAD_TO_DEG;
    }

    if (imuAvailable && imuTurnActive) {
      // Giro cerrado en yaw: acumular el giro real con unwrap incremental y
      // re-apuntar el arco restante en cada ciclo. El objetivo lo define el
      // IMU, no la geometría supuesta — rueda loca, stiction y wheel_dist
      // dejan de producir déficit.
      float dYaw = yaw - imuTurnPrevYaw;
      if (dYaw >  180.0f) dYaw -= 360.0f;
      if (dYaw < -180.0f) dYaw += 360.0f;
      imuTurnAccumDeg += dYaw * yawScale;  // grados físicos, no crudos del gyro
      imuTurnPrevYaw   = yaw;

      if (imuTurnSettleUntil != 0) {
        // Motores ya cortados: seguir midiendo hasta que el coast termine,
        // así la verificación final incluye la inercia (la cámara mostraba
        // 2-12° de giro extra después del corte que el IMU no contaba)
        if (millis() < imuTurnSettleUntil) {
          break;
        }
        imuTurnSettleUntil = 0;

        float delta = imuTurnAccumDeg;           // unwrapped: válido >180°
        float error = imuTurnTargetDeg - delta;  // positivo = giró de menos
        MessageDebugf("DEBUG: -1, ID: %s, TURN IMU: objetivo=%.1f° real=%.1f° error=%.1f° corr#%d (yaw %.1f→%.1f)",
                      robotID.c_str(), imuTurnTargetDeg, delta, error,
                      imuTurnCorrCount, imuTurnStartYaw, yaw);

        if (abs(error) > imuTurnTolerance &&
            imuTurnCorrCount < imuTurnMaxCorrections) {
          // Closed-loop iterativo: encolar otra corrección y volver a medir
          // tras su settle. Ya no es de un solo tiro — itera hasta |error|<tol
          // o agotar imuTurnMaxCorrections. La corrección corre SIN brake-lead
          // (ver rama de manejo) para que el arco chico no se cancele solo.
          float corrArc = radians(error) * centerToWheelDistance;
          fsmInstruction[0] = TURN;
          fsmInstruction[1] = corrArc;
          instructionList.push_front(fsmInstruction);
          imuTurnIsCorrection = true;
          imuTurnCorrCount++;
          MessageDebugf("DEBUG: -1, ID: %s, TURN corrección #%d: %.1f° (arc=%.1fmm)",
                        robotID.c_str(), imuTurnCorrCount, error, corrArc);
        } else {
          imuTurnIsCorrection = false;
          imuTurnCorrCount    = 0;
        }
        imuTurnActive = false;
        movementReady = true;
      } else {
        float leftTraveled  = movement.leftPulseCount * millimetersPerPulse;
        float rightTraveled = movement.rightPulseCount * millimetersPerPulse;

        // Failsafe: si el yaw no avanza (IMU muda/congelada), cerrar por
        // encoders para no girar infinito
        if (fabs(leftTraveled) > fabs(instructionValue) * 1.5f + 20.0f) {
          MessageDebugf("DEBUG: -1, ID: %s, TURN failsafe: yaw estancado "
                        "(%.1f° de %.1f°), cierro por encoders",
                        robotID.c_str(), imuTurnAccumDeg, imuTurnTargetDeg);
          imuTurnActive       = false;
          imuTurnIsCorrection = false;
          imuTurnCorrCount    = 0;
          movementReady       = true;
        } else {
          // Frenar imuTurnBrakeLead antes del objetivo: la inercia completa el
          // giro. PERO en una corrección el arco es chico y no hay momento que
          // costear → lead=0; con lead la corrección se cancelaría a sí misma.
          float lead = imuTurnIsCorrection
                           ? 0.0f
                           : ((imuTurnTargetDeg >= 0) ? imuTurnBrakeLead
                                                      : -imuTurnBrakeLead);
          float remainingArc =
              radians(imuTurnTargetDeg - lead - imuTurnAccumDeg) *
              centerToWheelDistance;
          bool reached = MoveDistanceByWheel(leftTraveled + remainingArc,
                                             rightTraveled - remainingArc);
          if (reached) {
            ConfigureHBridge(0, 0);
            imuTurnSettleUntil = millis() + imuTurnSettleMs;
          }
          movementReady = false;  // el giro termina tras el settle
        }
      }
    } else {
      movementReady = MoveDistanceByWheel(instructionValue, -instructionValue);
    }

    if (movementReady) {
      MessageDebugf("DEBUG: -1, ID: %s, Giro completado", robotID.c_str());
      intContext.Clear();
      isEvading = false;
      state = STOP;

    } else if (obstacles.HasAnyObstacle() && !isEvading) {
      obstacles.UpdateBitmap();

      intContext.wasInterrupted = true;
      intContext.previousState = TURN;
      intContext.leftPulsesBeforeStop = movement.pastLeftPulseCount;

      float traveled = movement.pastLeftPulseCount * millimetersPerPulse;
      intContext.remainingValue = instructionValue - traveled;

      isEvading = true;
      evasionStartTime = millis();

      float angleRemaining =
          (intContext.remainingValue / centerToWheelDistance) * RAD_TO_DEG;
      MessageDebugf("DEBUG: -1, ID: %s, TURN interrumpido: restante=%.1f°",
                    robotID.c_str(), angleRemaining);

      if (obstacles.centralObstacle) {
        movementReady = false;
      }

      imuTurnActive = false;  // cancelar seguimiento IMU si el giro fue interrumpido
      imuTurnIsCorrection = false;
      imuTurnCorrCount = 0;
      state = STOP;
    }

    break;
  }

  case RANDOM_WALK: {
    if (previousMillisRW == 0) {
      previousMillisRW = millis();
    }

    currentMillis = millis();
    millisDifference = currentMillis - previousMillisRW;
    if (millisDifference < instructionValue) {
      previousMillisRW = currentMillis;
      fsmInstruction[0] = RANDOM_WALK;
      fsmInstruction[1] = instructionValue - millisDifference;
      instructionList.push_front(fsmInstruction);
      SelectMovementRW();
    } else {
      previousMillisRW = 0;
      MessageDebugf("DEBUG: -1, ID: %s, Random Walk terminado",
                    robotID.c_str());
    }

    state = READ_INSTRUCTION;
    break;
  }

  case REVERSE: {
    movementReady = MoveDistanceByWheel(reverseDistance, reverseDistance);

    if (movementReady) {
      obstacleDetected = true;
      MessageDebugf("DEBUG: -1, ID: %s, Retroceso completado", robotID.c_str());
      state = STOP;
    } else if (obstacles.HasAnyObstacle() && !isEvading) {
      MessageDebugf("DEBUG: -1, ID: %s, Obstáculo durante retroceso!",
                    robotID.c_str());
      state = STOP;
    }

    break;
  }

  case STOP: {
    ConfigureHBridge(0, 0);

    if (movementReady == true) {
      if (!intContext.wasInterrupted) {
        isEvading = false;
        resumeScheduled = false;
      }
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

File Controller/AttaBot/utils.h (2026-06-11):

/***************************************************************************************
 * utils.h - VERSIÓN COMPLETA REFACTORIZADA
 * 
 * Este archivo contiene TODAS las estructuras de datos y clases auxiliares
 * que no dependen directamente de hardware (motores, sensores, WiFi)
 * 
 * Proyecto: AttaBot - Sistema de Robot Enjambre
 * Autor: 
 * Fecha: 2025
 ***************************************************************************************/

#ifndef UTILS_H
#define UTILS_H

#include <Arduino.h>
#include <deque>
#include <map>
#include <array>

// ============================================================================
// ESTRUCTURAS DE DATOS BÁSICAS
// ============================================================================

/***************************************************************************************
 * Estructura que representa la pose de un robot en un espacio bidimensional.
 ***************************************************************************************/
struct pose {
  float x, y, angle;

  pose(float x, float y, float angle) : x(x), y(y), angle(angle) {}
};


/***************************************************************************************
 * Estructura que representa los parámetros del controlador PID.
 ***************************************************************************************/
struct pidConstants {
  float kp, ki, kd;

  pidConstants(float p, float i, float d) : kp(p), ki(i), kd(d) {}
};


/***************************************************************************************
 * Estructura que representa un filtro de Kalman.
 ***************************************************************************************/
struct kalmanFilter {
  float R; // Valor R filtro de Kalman
  float H; // Valor de ganancia filtro de Kalman
  float Q; // Valor Q filtro de Kalman
  float P; // Valor de ajuste de Kalman
  float K; // Valor ganancia K de Kalman
  float predictedValue; // Valor predicho

  kalmanFilter(float r, float h, float q)
      : R(r), H(h), Q(q), P(0), K(0), predictedValue(0) {}

  void Reset() {
    P = 0;
    K = 0;
    predictedValue = 0;
  }

  float Calculate(float val) {
    K = (P * H) / (H * P * H + R);
    predictedValue = predictedValue + K * (val - H * predictedValue);
    P = (1 - K * H) * P + Q;
    return predictedValue;
  }
};


/***************************************************************************************
 * Estructura para un controlador PID con filtro de Kalman.
 ***************************************************************************************/
struct pidController {
  kalmanFilter kf;
  pidConstants pidConst;
  const float samplingTime;
  const float minWorkCycleLimit;
  const float maxWorkCycleLimit;
  float offsetSumError;
  float sumError;
  float previousError;
  float error;
  float differentialError;

  pidController(kalmanFilter k, pidConstants p, float tiempo, float limiteMin, float limiteMax)
      : kf(k), pidConst(p), sumError(0), previousError(0), error(0), offsetSumError(0),
        samplingTime(tiempo), minWorkCycleLimit(limiteMin), maxWorkCycleLimit(limiteMax) {}

  void Reset() {
    sumError = 0;
    previousError = 0;
    kf.Reset();
  }

  int Calculate(const float reference, const float currentValue) {
    error = reference - currentValue;
    sumError += error * samplingTime;
    sumError = constrain(sumError, -maxWorkCycleLimit, maxWorkCycleLimit);
    float pidPwm = (pidConst.kp * error) + (pidConst.ki * sumError);
    differentialError = (abs(pidPwm) < minWorkCycleLimit) ? (error - previousError) / samplingTime : 0;
    pidPwm += pidConst.kd * differentialError;
    pidPwm = kf.Calculate(pidPwm);

    // Anti-windup mejorado: si estamos en saturación, no acumular error
    float constrainedPwm = constrain(pidPwm, -maxWorkCycleLimit, maxWorkCycleLimit);
    if (abs(constrainedPwm) >= maxWorkCycleLimit && abs(pidPwm) > abs(constrainedPwm)) {
      // Estamos saturados y queremos ir más allá: revertir acumulación
      sumError -= error * samplingTime;
    }

    previousError = error;
    return static_cast<int>(constrainedPwm);
  }
};


/***************************************************************************************
 * Estructura que almacena los valores de bias para sensores IMU.
 *
 * Los valores se persisten mediante Preferences (namespace "attabot-config"),
 * por lo que no se necesitan campos de integridad (header/checksum).
 * La validez se determina verificando si la clave existe en Preferences.
 ***************************************************************************************/
struct biasStore {
  int32_t biasGyroX  = 0;
  int32_t biasGyroY  = 0;
  int32_t biasGyroZ  = 0;
  int32_t biasAccelX = 0;
  int32_t biasAccelY = 0;
  int32_t biasAccelZ = 0;
  int32_t biasCPassX = 0;
  int32_t biasCPassY = 0;
  int32_t biasCPassZ = 0;

  // Retorna true si al menos el bias de giroscopio X fue guardado anteriormente.
  bool IsValid() const {
    return biasGyroX != 0 || biasGyroY != 0 || biasGyroZ != 0;
  }

  void Clear() {
    biasGyroX  = 0; biasGyroY  = 0; biasGyroZ  = 0;
    biasAccelX = 0; biasAccelY = 0; biasAccelZ = 0;
    biasCPassX = 0; biasCPassY = 0; biasCPassZ = 0;
  }
};


// ============================================================================
// AUTOTUNING PID — Relay Method (Åström-Hägglund)
// ============================================================================
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

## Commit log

2024-12-02 Add 3D and 2D files of the robot chassis
    [base.SLDPRT, baseAPDS1.SLDPRT, baseAPDS2.SLDPRT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]
2024-12-02 Add Docs
    [SystemVisionIdentifiers.dwg]
2025-07-02 Test Data para paper Navigation
    [Cob_10min_Gen.csv, Cob_15min_3Rob.csv, Cob_15min_Gen.csv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]
2025-09-17 feat(controller): replace Freenove with FastLED and Servoesp32 with ESP32Servo
    Includes a new debugging function for quick testing using a serial prompt.
    [AttaBot.ino]
2025-09-17 feat(controller): update multiple files in Chassis folder
    [APDS9960.SLDPRT, IRsensors.SLDPRT, LiPoBattery.SLDPRT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]
2025-09-29 feature:(BaseController) Prueba 2 sistema de congregacion. receptor de menajes
2025-11-27 Actualizar formato de funciones
2026-02-09 Snapshot of current state: Update Base and Controller logic, add setup documentation and tools
2026-02-10 feat: Implement Bug 2 algorithm infrastructure (Phase 1)
    - Add Bug2State struct to utils.h with M-Line math, hit point tracking,
    loop detection, and timeout logic
    - Add new FSM states: BUG2_SEEK, BUG2_WALL_FOLLOW, BUG2_REQUEST_POSITION
    - Add Bug2 navigation functions: InitiateBug2Navigation, Bug2ProcessPosition,
    Bug2WallFollowStep
    - Add BUG2|X|Y UDP command for initiating Bug2 navigation
    - Hook Bug2 into POSITION_RESPONSE and RESUME_AFTER_EVASION handlers
    - Add FSM case entries for obstacle detection transitions during Bug2
    [AttaBot.ino, utils.h]
2026-04-29 fix: ArUco migration, Bug2 Phase 1, sendPositionToRobot fix
    - Migración completa de detección por color HSV a markers ArUco (DICT_4X4_50)
    - Implementación de algoritmo Bug 2 en controlador (BUG2_SEEK, BUG2_WALL_FOLLOW, BUG2_REQUEST_POSITION)
    - Refactor de estructuras en utils.h (Bug2State, EvasionTracker, NavigationTarget, etc.)
    - Fix: sendPositionToRobot usaba previousPose (estale) — ahora usa getPose() para dato en tiempo real
    [AttaBot.ino, utils.h]
2026-04-30 fix: camera pipeline, ArUco detection, setup stability (lab session 2026-04-30)
    - Fix: cv2.undistort → remap con mapas pre-computados (3-5x más rápido)
    - Fix: MJPEG + BUFFERSIZE=1 para cámara a 30 FPS sin crashes
    - Fix: escalar matriz de cámara automáticamente si resolución ≠ 1920x1080
    - Fix: detección ArUco en media resolución (4x más rápido)
    - Fix: QT_QPA_PLATFORM=xcb al inicio para evitar bloqueo de imshow en Wayland
    - Fix: setupRobots mantenía robotIP=None tras cada fallo de detección → TURN|90 infinito
    - Fix: retry counter (15 frames) antes de reenviar TURN|90 en setup
    - Fix: os.makedirs para directorio Logs/ faltante
    - Tune: parámetros ArUco balanceados (14 iteracion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
2026-05-08 fix: Bug2 wall-follow no funciona a la izquierda ni se mantiene en pared
    Tres bugs raíz identificados:
    1. obstacles.Clear() en ACTIVE_EVASION destruía el estado de sensores antes de
    Bug2WallFollowStep, dejando al robot sin información de pared y agotando
    lostWallSteps en 3 pasos sin haber detectado nada.
    2. wallFollowDirection nunca se asignaba automáticamente (siempre 1/derecha),
    por lo que el sensor izquierdo era ignorado por completo en WallFollowStep.
    3. maxLostWallSteps=3 era insuficiente (600mm de margen antes de abandonar pared).
    Fixes aplicados:
    - Eliminado obstacles.Clear() en el handler Bug2 de ACTIVE_EVASION
    - Bug2WallFollowStep: auto-detecta dirección en primer pas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
    [AttaBot.ino, utils.h]
2026-05-14 fix: Bug2 ShouldLeaveWall, mLineThreshold, maxLostWallSteps, state in REQUEST_POSITION
    - ShouldLeaveWall: reemplaza guard de minStepsBeforeLoopCheck con verificación de
    proyección (+100mm sobre hitPoint en dirección Start→Goal). Permite salida temprana
    en obstáculos pequeños sin salir prematuramente en el hitPoint.
    - mLineThreshold: 60mm → 150mm para capturar cruces de línea M cuando el obstáculo
    está desplazado de la línea (validado en lab: obstáculo a ~97mm de la línea M).
    - maxLostWallSteps: 6 → 3 (90° de búsqueda suficiente para esquinas convexas,
    reduce ciclos de espera a la mitad).
    - BUG2_REQUEST_POSITION: incluye estado del robot en el mensaje
    (REQUEST_POS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
    [AttaBot.ino, utils.h]
2026-05-14 feat: sistema de coordenadas ArUco con origen configurable y STATUS mejorado
    - configSystem.json: origin_x_mm/origin_y_mm para definir origen del arena.
    Calibrado a esquina superior izquierda del lab (arena ~2450×1510mm).
    - AttaBot_Base.py: aplica offset de origen al extraer coordenadas de tvec,
    todas las poses ArUco ahora son relativas al origen del arena.
    - STATUS: muestra posición y ángulo actual de cada robot con las nuevas coordenadas.
    - Bug2 REQUEST_POSITION: log muestra estado [SEEK/WALL paso=N dist=Xmm].
2026-05-14 fix: OTA paths — bin path y versión de espota.py
2026-05-29 feat: ReactiveNav — arquitectura unificada GT+congregación+evasión reactiva
    Reemplaza Bug2 como sistema de navegación principal por ReactiveNav:
    - Una función ReactiveNavStep() para GT y congregación (misma lógica)
    - Evasión reactiva integrada: bias de ángulo basado en IR, sin cambio de modo
    - Dirección de evasión frontal elegida automáticamente hacia el lado del objetivo
    - Segmentos más cortos durante evasión (120mm) para correcciones más frecuentes
    Otros cambios:
    - IMU-assisted TURN: corrección post-giro con giroscopio, ±3° tolerancia
    - centerToWheelDistance configurable vía NAV_CONFIG|WHEEL_DIST
    - angle_offset y wheel_distance por robot en configSystem.json
    - EMA de A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
    [AttaBot.ino, utils.h]
2026-05-29 fix: CONGREGATION reset nav, GET_STATUS muestra nav en vez de bug2
    [AttaBot.ino]
2026-05-29 feat: simulación 2D AttaBot con ReactiveNav
    5 escenarios: GT básico, GT con barrera, congregación 3 robots,
    comparativa turn_factor, impacto angle_offset ArUco.
    Valida que:
    - ReactiveNav autocorrige subgiro de motor (100% éxito con factor=0.77)
    - Marker rotado 90°+ destruye navegación completamente (0% éxito)
    - Congregación converge en 3-4 pasos desde cualquier posición
    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
2026-05-29 fix: sim — colisión continua durante MOVE, IR solo obstáculos físicos, separación robot-robot
    - Sub-pasos de 20mm con chequeo de colisión y IR durante el movimiento
    - IR solo detecta obstáculos físicos (no otros robots, igual que firmware)
    - collides() solo chequea obstáculos estáticos
    - Congregación 3/3 llegan en 2-4 pasos
    Limitación documentada: obstáculo que bloquea trayectoria directa requiere
    algo más que el bias reactivo puro — próximo paso: persistencia de evasión.
2026-06-11 feat: congregación con parking slots — slot único por seguidor en círculo de 200mm
    Base asigna CONGREGATION|líder|idx|total por unicast; firmware calcula
    punto de estacionamiento alrededor del líder. Validado en sim 2D.
2026-06-11 fix: GT validado en hardware — IMU FIFO drain, TURN robusto, SENSOR_MASK, setup snapshot
    Firmware:
    - LeerYaw drena el FIFO del DMP (~112Hz vs lectura 50Hz) y elimina
    resetFIFO que corrompía lecturas — causa del yaw congelado en giros
    - TURN IMU: error wrapped a [-180,180] (TURN|180 generaba corrección
    de 359°), máximo una corrección por giro, tolerancia 10°
    - SENSOR_MASK|L/R/C|0/1 — ignora sensores IR con falsos positivos
    (IR izquierdo fantasma durante movimiento, pendiente fix hardware)
    - NAV_CONFIG ahora actualiza nav (ReactiveNav) además de bug2 legacy
    Base:
    - Setup: desplazamiento angular comparado contra snapshot pre-giro,
    con debug por segundo — evita timeout po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
    [AttaBot.ino]
2026-06-12 feat: giro closed-loop en yaw con calibración de escala de gyro por robot
    - TURN cerrado en IMU: re-apunte continuo del arco restante con unwrap
    (soporta >180°), brake-lead 3° + settle 400ms para incluir la inercia
    en la verificación, failsafe por encoders si el yaw se estanca
    - yawScale por robot persistente (NAV_CONFIG|YAW_SCALE|x|SAVE): gyros
    con error de escala ±2.4% medido vs ArUco (Atta_1=1.0240, Atta_2=0.9763)
    - POSE: re-sincroniza con la cámara tras 3 saltos bruscos consecutivos
    (antes quedaba atrapado ignorando para siempre tras mover el robot)
    - Base: marker de referencia (origen) excluido de la detección de robots
    - Config: origen ahora marker 0, wheel_distance remo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
    [AttaBot.ino]
2026-06-12 feat: rutina de calibración por robot (CALIBRATE.id) con cámara como patrón
    Estado de calibración repetible para cada Atta. Comando de consola
    CALIBRATE.<id> ejecuta:
    - Fase 1 (gyro): yaw_scale=1.0 temporal, 3×TURN|360, escala = giro físico
    ArUco / giro IMU → NAV_CONFIG|YAW_SCALE|x|SAVE (los giros son adimensionales,
    inmunes a la escala métrica de la cámara)
    - Fase 2 (encoders): PPR nominal temporal, 3×MOVE|500 con TURN|180 entre
    avances, PPR = nominal × 500/medido → SETPPR|x|SAVE
    Medición robusta: baseline con robot quieto ANTES del comando, ventanas de
    reposo de 0.8s promediadas (inmune al jitter ArUco), unwrap continuo del
    ángulo. IR enmascarados durante la rutina (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
2026-06-27 chore: limpieza de repo + fixes pre-EKF y herramientas de base/sim
    - partitions.csv (min_spiffs): flash 90%→60%, OTA y NVS (calibración) intactos
    - AttaBot.ino: fix giro closed-loop TURN (lead=0 en corrección, iterativo)
    - atta_test/: sketch de prueba; AttaBot_VClaude.cpp: variante de firmware
    - Base/: AttaBot_GUI.py, turn_check.py
    - .gitignore: ignora build/, Logs/, Base/Logs/, sim_output_*.png
    - destrackea Controller/AttaBot/build/ (artefactos regenerables)
    [partitions.csv]
2026-07-03 chore: retirar archivos de trabajo local del repo (copias de desarrollo, harness de pruebas, zip 3D redundante con los SLDPRT extraídos)
